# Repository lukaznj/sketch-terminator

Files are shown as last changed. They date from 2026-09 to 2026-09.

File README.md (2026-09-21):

# Sketch Terminator

A 3-DOF robot arm that draws lines between objects it can see.

Point a webcam at a sheet of paper with some objects on it, tell the robot
*"draw a line from the car to the traffic light, but avoid the cat"* in plain
English, and it finds them, plans a path that goes around the cat, and draws it
with a marker.

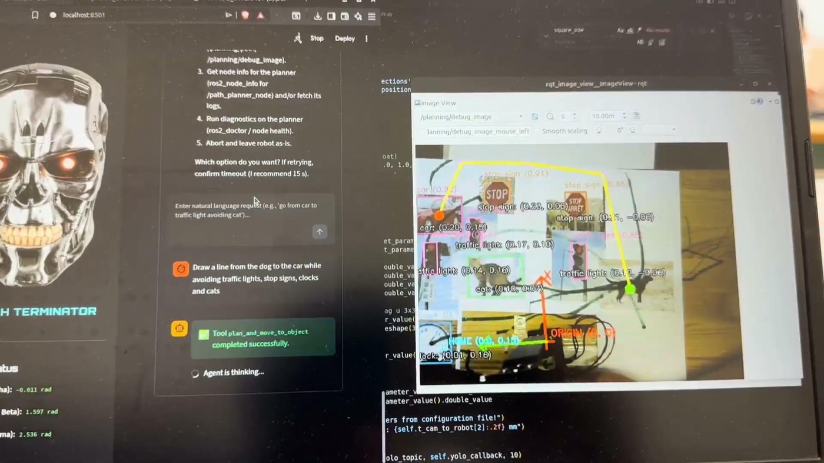
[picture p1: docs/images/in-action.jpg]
The robot in action


---

## What it does

1. **Sees.** A YOLO model detects objects in the camera image, and a
   calibrated projection turns each detection's pixels into real coordinates
   in the robot's own frame.
2. **Plans.** A visibility graph plus A\* finds the shortest path between two
   objects that stays clear of the ones you asked it to avoid.
3. **Draws.** The path is resampled into a constant-speed stream of points,
   inverse kinematics turns each one into joint angles, and the arm draws it,
   lifting the marker for the approach and retreat.
4. **Listens.** An LLM agent ([ROSA](https://github.com/nasa-jpl/rosa)) sits on
   top with tools for each of the above, so the whole thing can be driven
   conversationally.

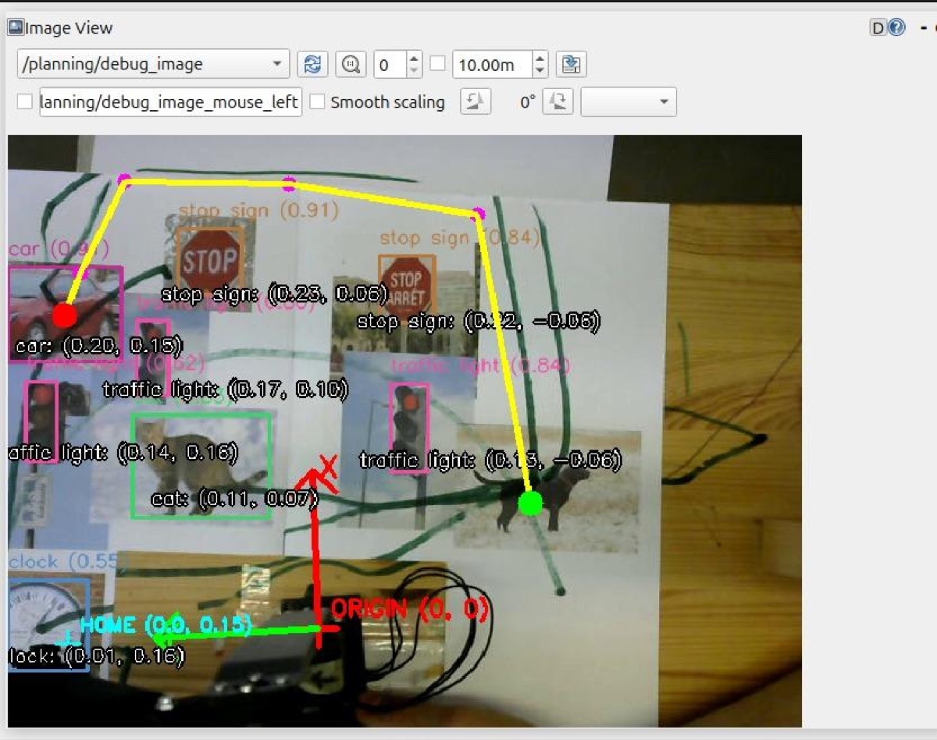
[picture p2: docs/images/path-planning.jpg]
Planned path, drawn back into the camera view


*The planner's debug view: detections in pink, the planned path in yellow,
the robot's origin and axes in red and green.*

## The robot

| | |
|---|---|
| **Joints** | 3: base rotation, shoulder, elbow |
| **Servos** | Dynamixel XL430-W250, IDs 11/12/13 on one 1 Mbps TTL bus |
| **Reach** | ~45 cm (200 mm + 253 mm links) |
| **Drawing speed** | 10 cm/s |
| **Camera** | Any UVC webcam, fixed overhead, 640 × 480 |
| **End effector** | Spring-loaded marker holder, so no fourth axis is needed |
| **Structure** | 3D-printed links on a plywood base |

Full bill of materials, printable files and assembly notes:
**[`hardware/README.md`](hardware/README.md)**

## Architecture

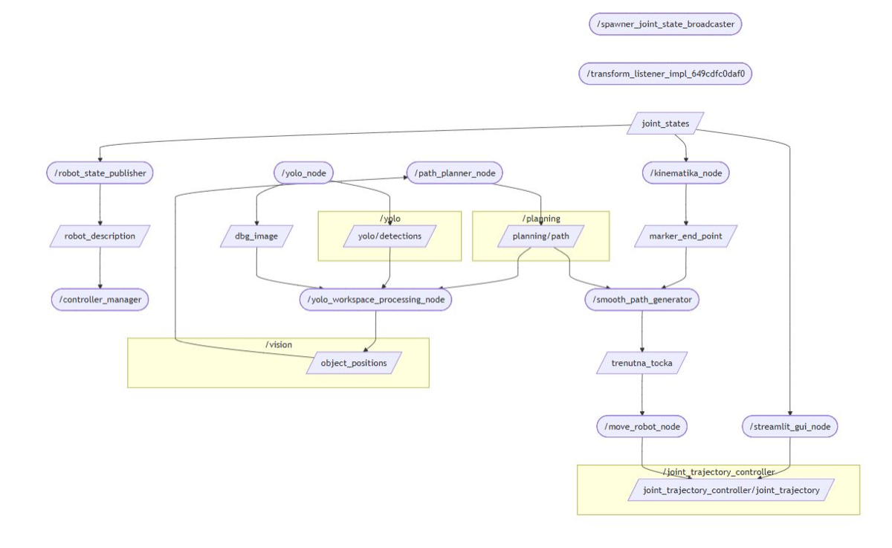
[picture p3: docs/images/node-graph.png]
ROS 2 node graph


The pipeline is a straight line, and each stage is a separate ROS 2 node:

```
camera ──► yolo_node ──► yolo_workspace_processing_node ──► path_planner_node
                                    │                              │
                                    │  /vision/object_positions     │ /planning/path
                                    ▼                              ▼
                                  (JSON)                 generate_smooth_path
                                                                   │ /current_point
                                                                   ▼
kinematics_node ◄── /joint_states ── controllers ◄── move_robot_node
      │                                                    (inverse kinematics)
      └──► /marker_end_point  (start pose for the path generator)
```

| Node | File | Job |
|---|---|---|
| `yolo_node` | [`yolo_node.py`](sketch_terminator/yolo_node.py) | Runs YOLO on the camera stream. |
| `yolo_workspace_processing_node` | [`yolo_workspace_processing_node.py`](sketch_terminator/yolo_workspace_processing_node.py) | Projects detections onto the paper plane; draws the debug overlay. |
| `path_planner_node` | [`path_planner_node.py`](sketch_terminator/path_planner_node.py) | ROS wrapper around the planner. |
| *(library)* | [`visibility_graph.py`](sketch_terminator/visibility_graph.py) | The actual planning: visibility graph + A\*. No ROS, runs standalone. |
| `smooth_path_generator` | [`generate_smooth_path.py`](sketch_terminator/generate_smooth_path.py) | Resamples the path at constant speed; adds pen-up approach and retreat. |
| `move_robot_node` | [`move_robot.py`](sketch_terminator/move_robot.py) | Inverse kinematics → joint trajectories. |
| `kinematics_node` | [`kinematics_node.py`](sketch_terminator/kinematics_node.py) | Forward kinematics from measured joint angles. |
| *(library)* | [`kinematics.py`](sketch_terminator/kinematics.py) | The arm's geometry and joint limits, in one place. |
| `agent_node` | [`agent_node.py`](sketch_terminator/agent_node.py) | The LLM agent, over ROS topics. |
| *(library)* | [`tools.py`](sketch_terminator/tools.py) | The tools the agent can call. |
| *(app)* | [`gui/dashboard.py`](gui/dashboard.py) | Streamlit control panel. |

Both pure-logic modules check themselves, with no test framework needed:

```bash
python3 sketch_terminator/kinematics.py        # IK/DK round-trip
python3 sketch_terminator/visibility_graph.py  # planner geometry
```

## The interface

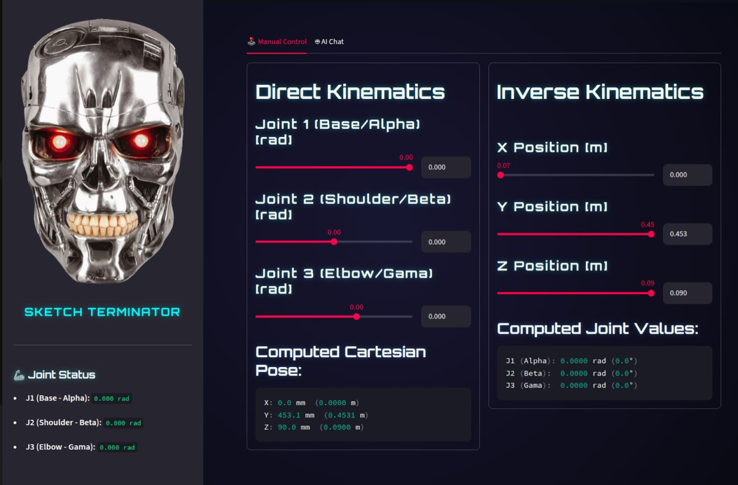
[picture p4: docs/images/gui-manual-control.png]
Manual control tab


The Streamlit dashboard has two tabs. **Manual Control** puts joint sliders
next to Cartesian sliders. Move either and the other follows, and the arm goes
with them. Poses that would drive the marker through the paper are refused.

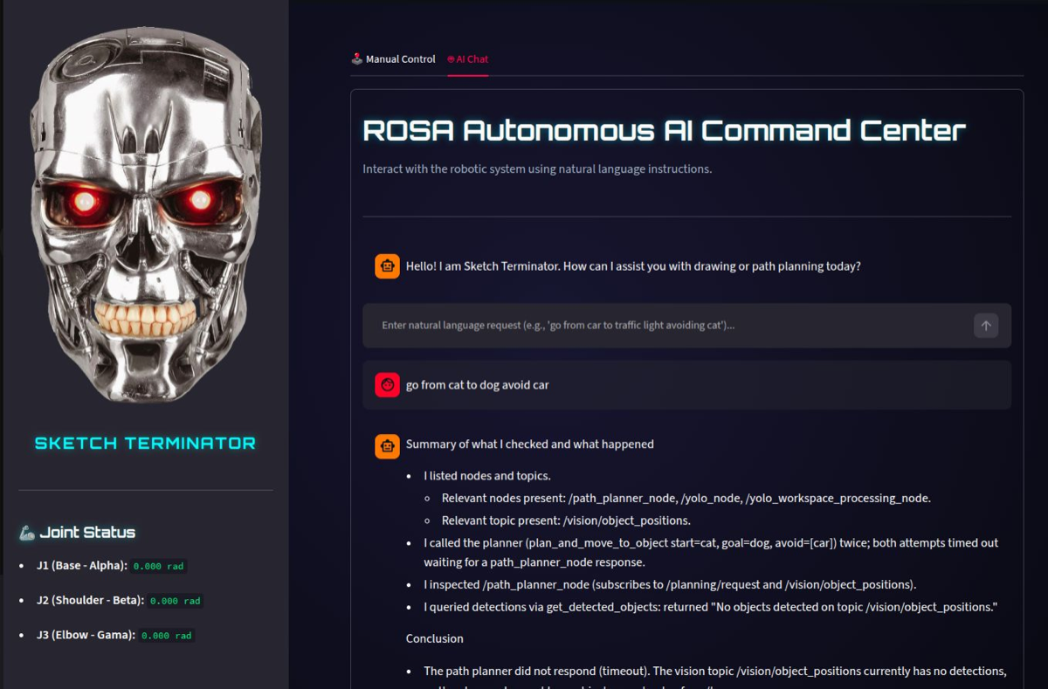
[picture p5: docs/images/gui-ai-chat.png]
AI chat tab


**AI Chat** talks to the ROSA agent, streaming its reasoning and showing which
tool it is running.

---

## Setup

### Prerequisites

- **Ubuntu 24.04** with **ROS 2 Jazzy** ([install guide](https://docs.ros.org/en/jazzy/Installation.html))
- An NVIDIA GPU is recommended for YOLO; it falls back to CPU automatically, just slowly.

### 1. ROS dependencies

```bash
sudo apt update && sudo apt install -y \
  ros-jazzy-ros2-control ros-jazzy-ros2-controllers \
  ros-jazzy-usb-cam ros-jazzy-camera-calibration \
  ros-jazzy-cv-bridge ros-jazzy-xacro ros-jazzy-rviz2 \
  python3-colcon-common-extensions
```

The Dynamixel hardware interface may or may not have a binary release for your
distro. Try apt first, and clone it into your workspace if that comes up empty:

```bash
sudo apt install -y ros-jazzy-dynamixel-hardware \
  || git clone https://github.com/dynamixel-community/dynamixel_hardware.git \
       ~/sketch_ws/src/dynamixel_hardware
```

### 2. Workspace and source

```bash
mkdir -p ~/sketch_ws/src && cd ~/sketch_ws/src
git clone https://github.com/lukaznj/sketch-terminator.git sketch_terminator
```

`yolo_msgs` is not in the ROS index, so clone it alongside:

```bash
git clone https://github.com/mgonzs13/yolo_ros.git
```

### 3. Python dependencies

```bash
pip install ultralytics streamlit python-dotenv rich \
            jpl-rosa langchain-openai
```

### 4. Build

```bash
cd ~/sketch_ws
colcon build --symlink-install
source install/setup.bash
```

Add the source line to your `~/.bashrc` so every new terminal has it.

### 5. API key

The LLM agent needs an OpenAI key. Everything else runs without one.

```bash
cd ~/sketch_ws/src/sketch_terminator
cp config/.env.example config/.env
# edit config/.env and paste your key
```

`config/.env` is gitignored. Do not commit it.

### 6. Hardware

- Set the servo IDs to **11**, **12**, **13** at **1 Mbps** with Dynamixel
  Wizard, before assembling the arm. See
  [`hardware/README.md`](hardware/README.md).
- Give yourself access to the serial port:
  ```bash
  sudo usermod -aG dialout $USER   # log out and back in
  ```
- Check which device the adapter and the camera came up as, and update
  [`urdf/sketch_terminator.ros2_control.xacro`](urdf/sketch_terminator.ros2_control.xacro)
  (`usb_port`) and [`config/camera_params.yaml`](config/camera_params.yaml)
  (`video_device`) if they are not `/dev/ttyUSB0` and `/dev/video0`:
  ```bash
  ls /dev/serial/by-id/
  v4l2-ctl --list-devices
  ```

## Calibration

**Do this before expecting the arm to draw in the right place.** Without it,
the vision pipeline has no idea where the camera is, and every position it
reports is wrong. Redo it whenever the camera moves.

Print a **9 × 7 inner corner** checkerboard, measure one square, and put the
real numbers in [`config/calib_config.yaml`](config/calib_config.yaml).

**Step 1, intrinsics** (lens geometry and distortion):

```bash
ros2 launch sketch_terminator camera_calib.launch.py
```

Move the board around the frame until all four sample bars fill up, click
**CALIBRATE**, then **SAVE**. Copy the resulting values into
[`config/camera_calibration_params.yaml`](config/camera_calibration_params.yaml).

**Step 2, extrinsics** (where the camera is, relative to the robot):

```bash
ros2 launch sketch_terminator camera_world.launch.py
```

Tape the board flat in view, measure its offset from the base of the arm, and
put those offsets in `calib_config.yaml`. The node prints a 4 × 4 transform;
copy its rotation into `R_cam_to_robot` and its translation (**in
millimetres**, so metres × 1000) into `t_cam_to_robot`, both in
[`config/vision_config.yaml`](config/vision_config.yaml).

**Step 3, check it.** Put a red marker at a spot you have measured and confirm
the position the node prints matches. If everything is off by a consistent
amount, trim `offset_x_m` / `offset_y_m` in `vision_config.yaml` rather than
redoing the transform.

## Running it

Everything at once, meaning hardware, vision, planning, RViz and the dashboard:

```bash
ros2 launch sketch_terminator master_robot.launch.py
```

Then open **http://localhost:8501**.

Vision and planning only, with no motors powered:

```bash
ros2 launch sketch_terminator vision.launch.py
```

To watch what the vision pipeline sees:

```bash
ros2 run rqt_image_view rqt_image_view /planning/debug_image
```

You can also drive it from the command line, without the GUI:

```bash
ros2 topic pub --once /planning/request std_msgs/String \
  '{data: "{\"start_class\": \"car\", \"goal_class\": \"traffic light\", \"avoid_classes\": [\"cat\"]}"}'
```

The class names are whatever your YOLO weights were trained on. The defaults
are the 80 COCO classes, which is why the demo uses cars, cats and traffic
lights.

## Troubleshooting

| Symptom | Cause |
|---|---|
| Arm does not move, no errors | The controllers spawned before the hardware was found. Check `ros2 control list_controllers`, and that the servos are powered (the U2D2 alone does not power them). |
| `Failed to open port` | Wrong `usb_port`, or you are not in the `dialout` group. |
| Arm moves to the wrong place | Calibration. Redo it, then trim `offset_x_m` / `offset_y_m`. |
| Nothing detected | Check `/dbg_image` first. Usually lighting, or objects the model was never trained on. |
| Agent times out | `agent_node` is not running, or `OPENAI_API_KEY` is missing from `config/.env`. |
| Arm jitters near its own base | Expected, because the base yaw is ill-conditioned there. `MIN_RADIUS` in `kinematics.py` keeps targets out of that region. |

## Repository layout

```
config/            camera, calibration and vision parameters
controllers/       ros2_control configuration
docs/              presentation and images
gui/               Streamlit dashboard
hardware/          printable parts, reference CAD, build guide
launch/            launch files
meshes/            STL meshes for the robot model
scripts/           camera-to-robot calibration tool
sketch_terminator/ the ROS 2 nodes
urdf/              robot model and hardware interface
```

## Documentation

The [project presentation](docs/presentation.pdf) covers the kinematics
derivation, the path planning approach and photos of the build.

## Team

Built by a five-person team for the Robotics Practicum course, 2025/2026.

## License

[Apache 2.0](LICENSE)

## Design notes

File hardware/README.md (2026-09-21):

# Hardware

Everything you need to build the arm: what to buy, what to print, and how it
goes together.

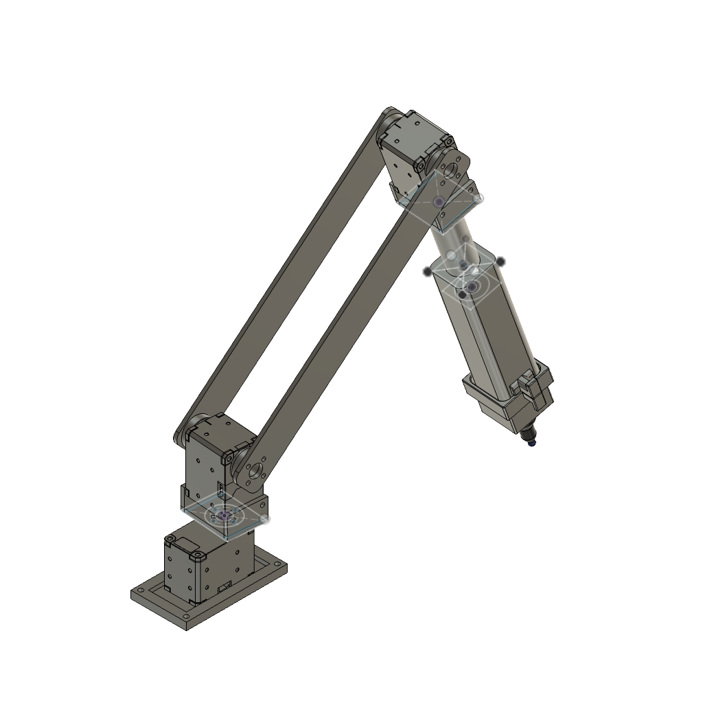
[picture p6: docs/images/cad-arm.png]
The assembled arm


## Bill of materials

| Part | Qty | Notes |
|---|---|---|
| Dynamixel **XL430-W250-T** servo | 3 | The whole arm. Any X-series servo with the same 28.5 × 46.5 × 34 mm body drops in without reprinting anything. |
| ROBOTIS **U2D2** USB adapter | 1 | Talks to the servo bus from the PC. |
| **U2D2 Power Hub** (or equivalent) | 1 | Injects 12 V into the daisy chain. |
| 12 V ≥ 2 A power supply | 1 | The XL430 is rated for 11.1 V; 12 V is the usual supply. |
| Dynamixel 3-pin TTL cables | 3–4 | One per servo plus one to the adapter. |
| **FP04-F2 / HN11-N1** style brackets | 2 | The frames that bolt onto the servo horns. Usually included with the servos. |
| M2.5 × 8 mm screws | ~20 | Servo mounting. |
| M3 × 12 mm screws + nuts | ~8 | Printed parts. |
| USB webcam (UVC, 640 × 480 or better) | 1 | Any webcam Linux exposes as `/dev/videoN`. |
| Whiteboard marker, ~18 mm barrel | 1 | Drops into the pen holder. |
| Compression spring, 9.5 × 17.5 mm | 1 | Keeps constant pressure on the paper. |
| Plywood / MDF base board | 1 | ~50 × 50 cm, plus an overhead frame for the camera. |

> The arm was built with **XL430-W250** servos. They are the cheap end of the
> X-series and are adequate here because the arm only carries a marker. They
> are plastic-geared, though, so do not add mass to the end effector without
> moving up to an XM430.

## Parts to 3D print

All files are in [`print/`](print/) as `.3mf`, exported from Fusion 360 and
ready to slice.

| File | Qty | What it is |
|---|---|---|
| [`base.3mf`](print/base.3mf) | 1 | Foot that bolts to the board and holds the base servo. |
| [`link-90-bracket.3mf`](print/link-90-bracket.3mf) | 1 | Right-angle bracket between the base servo and the shoulder servo. |
| [`long-link.3mf`](print/long-link.3mf) | 2 | The two parallel arm links. **Print two.** |
| [`pen-holder.3mf`](print/pen-holder.3mf) | 1 | Sleeve the marker slides into. |
| [`pen-holder-mount.3mf`](print/pen-holder-mount.3mf) | 1 | Carries the sleeve and bolts to the elbow servo. |
| [`pen-holder-stopper.3mf`](print/pen-holder-stopper.3mf) | 1 | Caps the sleeve and traps the spring. |

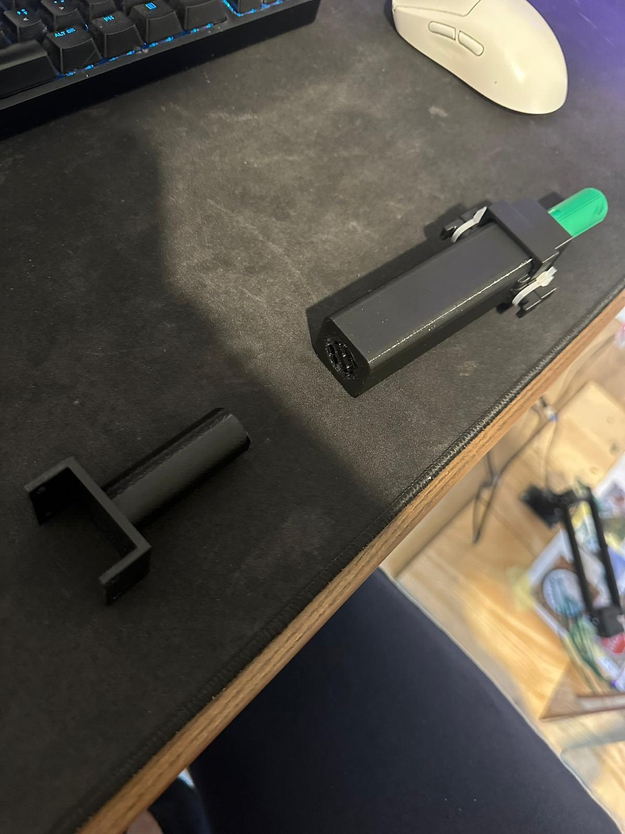
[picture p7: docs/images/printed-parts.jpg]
Printed parts


### Print settings

Nothing here is exotic. These settings were used for the parts in the photo:

| Setting | Value |
|---|---|
| Material | PLA |
| Layer height | 0.2 mm |
| Walls | 3 |
| Infill | 25 % gyroid |
| Supports | None needed; every part is oriented to print support-free |

The long links take the most load; if yours flex noticeably under the arm's own
weight, raise the wall count to 4 rather than the infill.

## Reference models

[`reference/`](reference/) holds geometry that is **not** printed. The servo
body, the marker and the spring are there so the assemblies show the real fit,
and the two assembly files are how the whole thing goes together.

| File | What it is |
|---|---|
| `full-arm-assembly.3mf` | The complete arm. Open this first to see how everything mates. |
| `pen-holder-assembly.3mf` | The end effector exploded out: sleeve, mount, stopper, spring, marker. |
| `dynamixel-xl430-w250.3mf` | Servo body, for fit checks. |
| `marker-pen.3mf` | The marker, for fit checks. |
| `compression-spring.3mf` | The spring, for fit checks. |
| `legacy-*.step` | Earlier design iterations, kept for reference. |

## The end effector

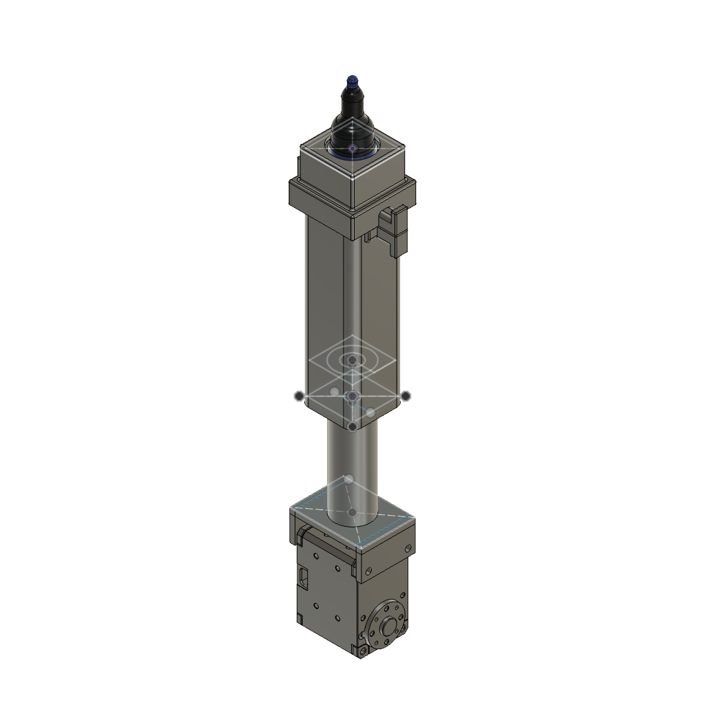
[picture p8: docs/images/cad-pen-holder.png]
Pen holder assembly


The marker is not driven up and down. The arm has only three joints, and all
three are used for positioning. Instead the marker floats inside its sleeve on
the compression spring:

- The arm drives the sleeve to **Z = 0**, slightly *into* the paper.
- The spring compresses and holds the tip down at roughly constant force.
- The stopper caps the top of the sleeve so the marker cannot be pushed out.

That means line weight stays even across the sheet without the paper having to
be perfectly flat or the Z calibration having to be perfect. It is also why
`Z_MAX` in the software is a hard limit: lifting past the shoulder pivot is
what clears the marker from the paper.

## Assembly notes

1. **Set the servo IDs first.** Connect each servo on its own with Dynamixel
   Wizard and set the IDs to **11** (shoulder), **12** (elbow) and **13**
   (base), all at **1 Mbps**. These are what
   [`urdf/sketch_terminator.ros2_control.xacro`](../urdf/sketch_terminator.ros2_control.xacro)
   expects. Doing this after assembly means taking the arm apart again.
2. **Centre every servo** (position 2048 / 180°) before bolting the horns on,
   so the mechanical zero matches the model's zero.
3. Bolt the base to the board. The arm's coordinate origin is the centre of the
   base servo's rotation axis, so measure everything else from there.
4. Daisy-chain the three servos and connect the chain to the U2D2, with the
   power hub injecting 12 V.
5. Mount the camera on an overhead frame looking straight down at the paper,
   roughly **65–70 cm** above it, with the whole drawing area in view and the
   arm's base at the edge of the frame. Anything rigid works; the one in the
   photos is scrap plywood.
6. Tape the calibration checkerboard flat inside the camera's view and measure
   its offset from the base. Those numbers go in
   [`config/calib_config.yaml`](../config/calib_config.yaml).

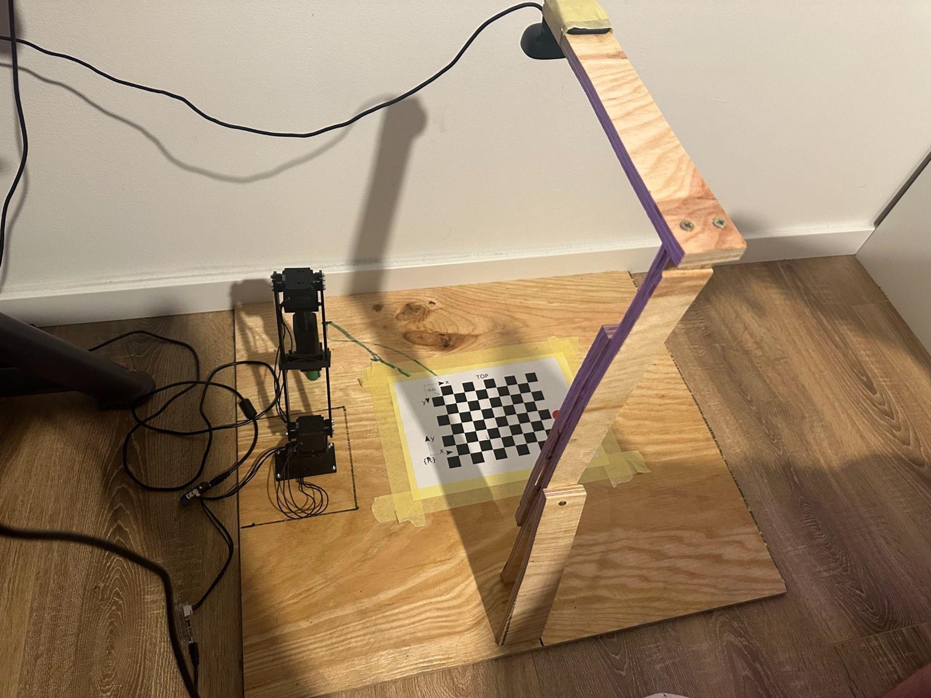
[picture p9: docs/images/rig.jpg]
The rig


Once it is built, follow the calibration steps in the
[main README](../README.md#calibration), because the arm cannot draw anywhere
near the right place until the camera is calibrated.

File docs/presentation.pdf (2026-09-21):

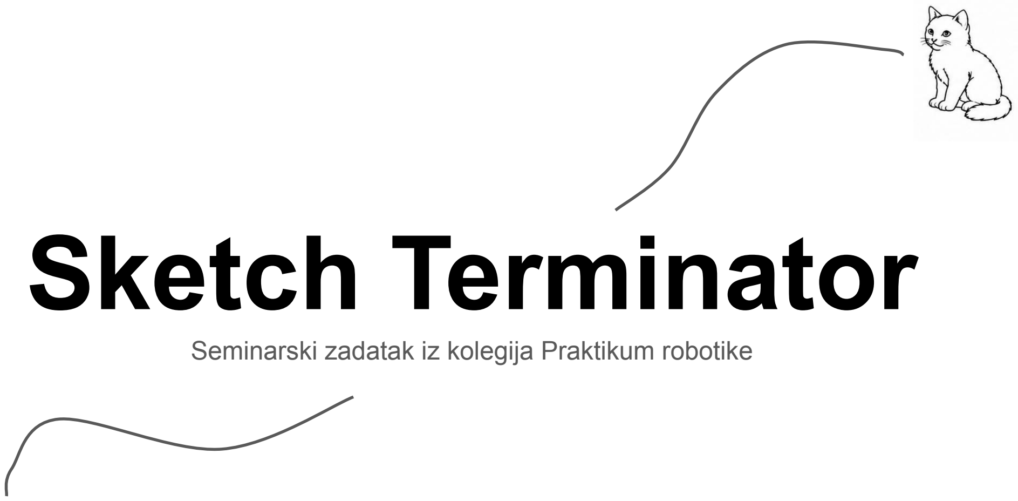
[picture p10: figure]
Sketch Terminator

Grupa SEM3 | Borna Dorontić, Josip Dugandžić, Ivan Marfat, Roko Milić, Luka Ražem | Ak. God. 2025/2026

Seminarski zadatak iz kolegija Praktikum robotike

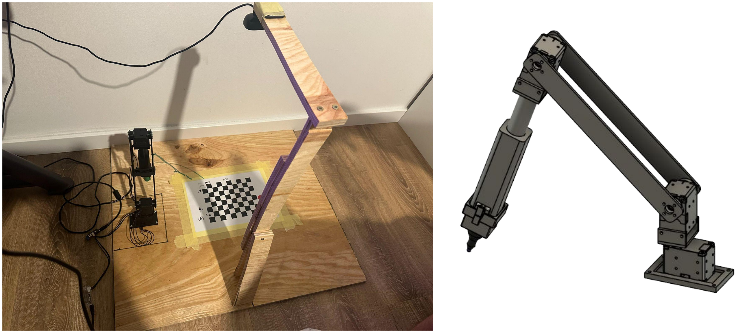
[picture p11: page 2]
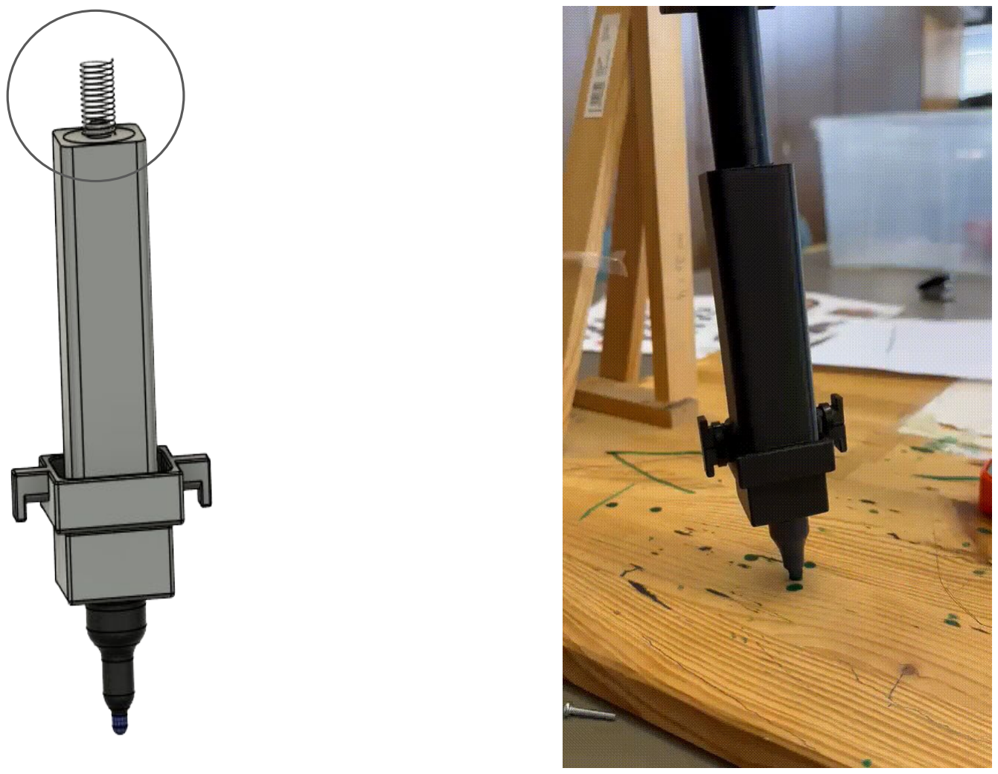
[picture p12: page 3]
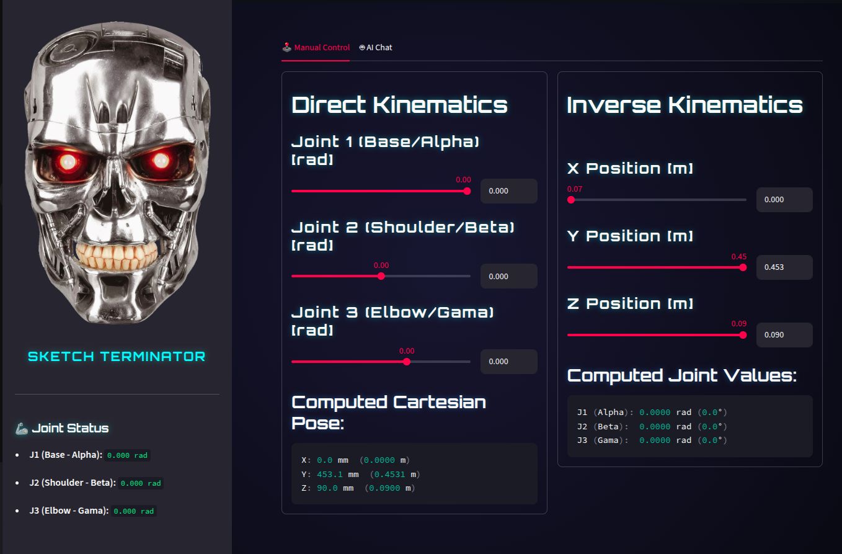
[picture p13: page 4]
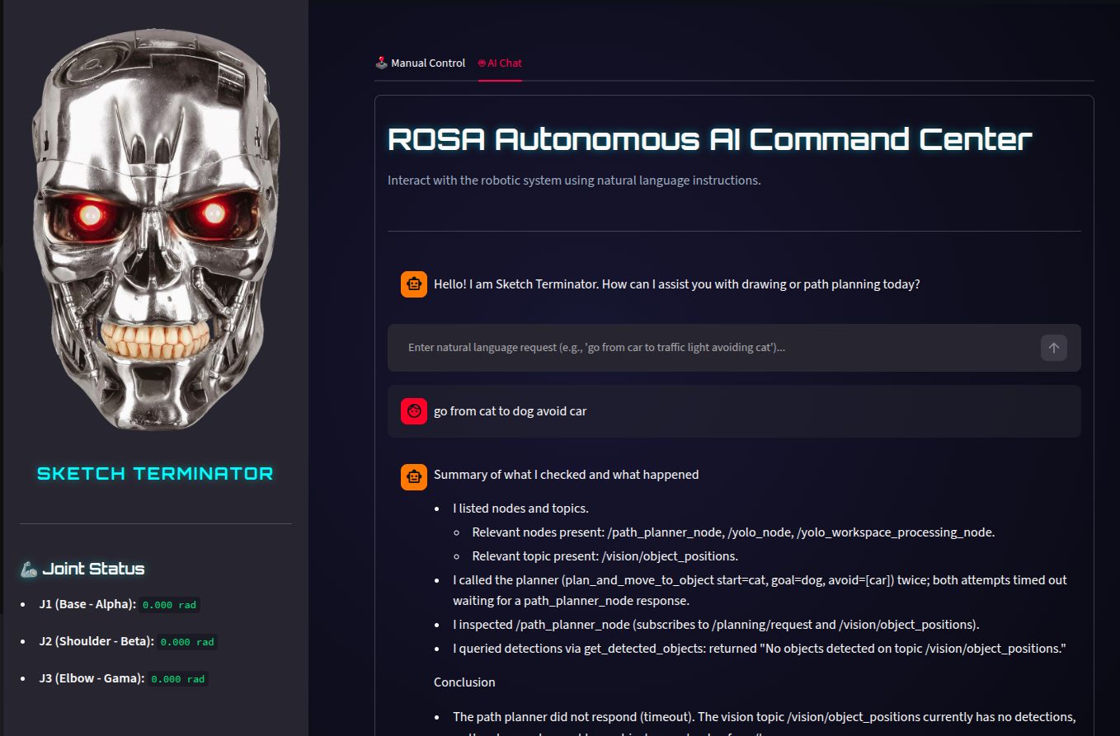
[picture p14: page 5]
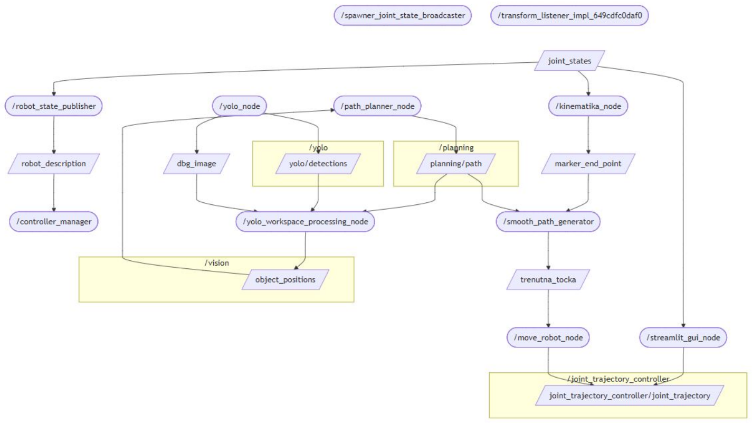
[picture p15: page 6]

## Path planning

- Sustav prima naredbu koje objekte

treba povezati i koje treba izbjeći

- Kamera detektira objekte i njihove

pozicije u radnom prostoru

- Algoritam provjerava prolazi li

direktna linija kroz prepreku

- Ako postoji prepreka, dodaje se

waypoint za zaobilaženje

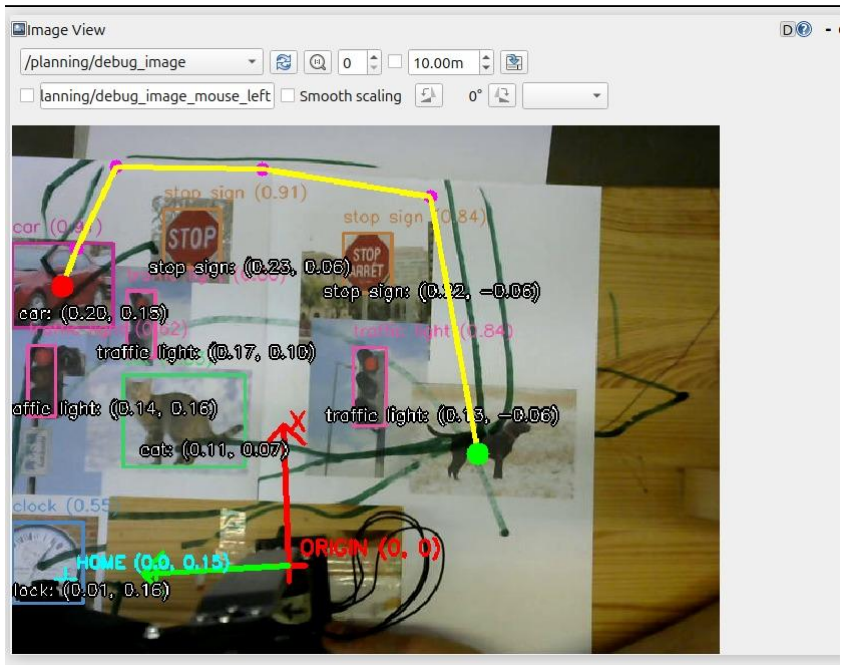
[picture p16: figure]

Primjer isplanirane putanje: žuta linija prikazuje isplaniranu putanju robota

## Inverzna kinematika i interpolacija puta

Node generate_smooth_path uzima točke koje šalje path_planner_node i generira glatku putanju u vremenu od ~100 točaka koje se šalju node-u za inverznu kinematiku

Točke šalje tako da se osigura sigurna brzina robota od oko 10cm/s

Osigurava da robot ne crta dok dolazi do početnog objekta, nakon crtanja vraća robota u poziciju gdje ne blokira pogled kameri

Node za inverznu kinematiku iz zadane točke računa i publisha potrebne zakrete motora

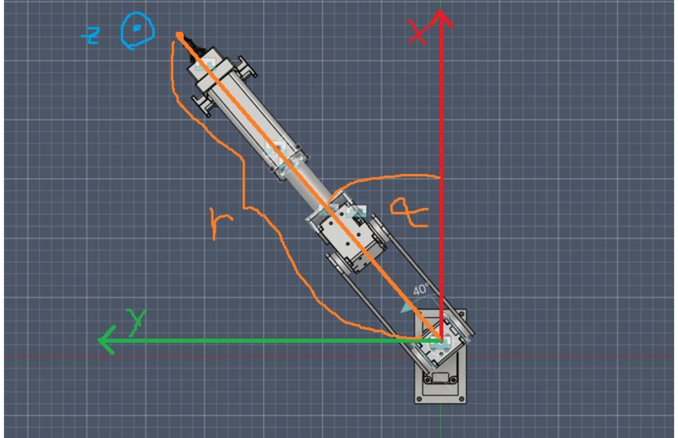
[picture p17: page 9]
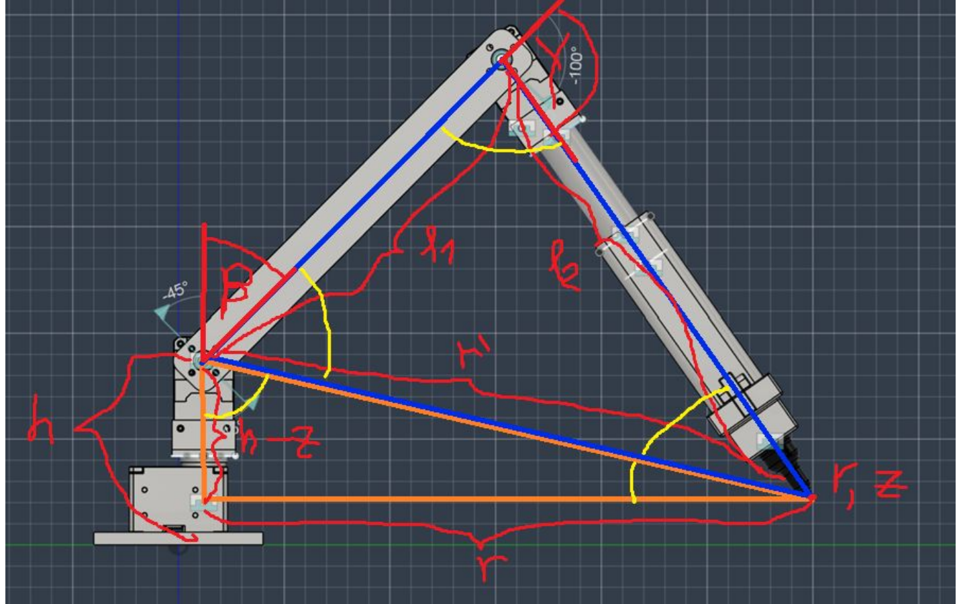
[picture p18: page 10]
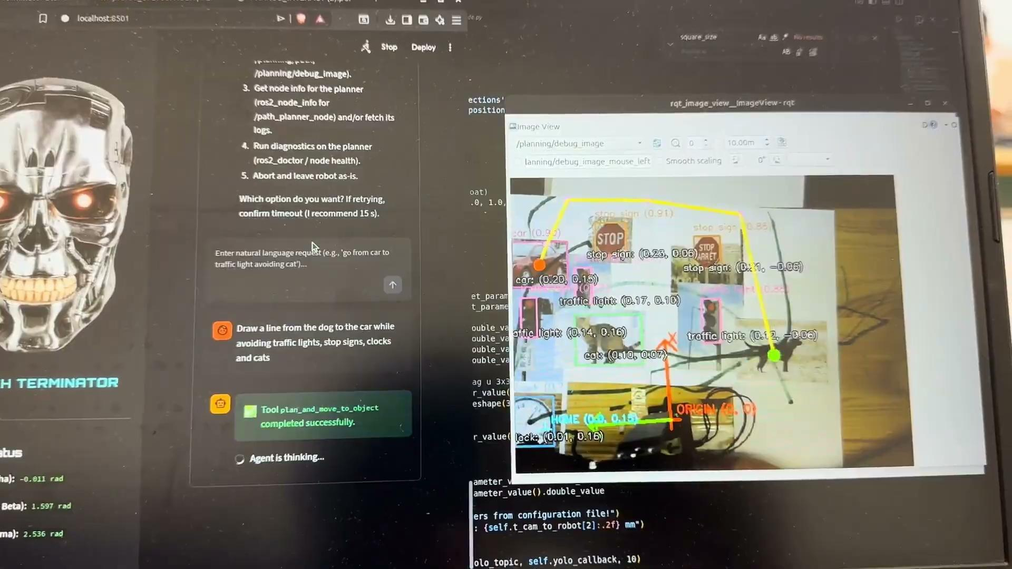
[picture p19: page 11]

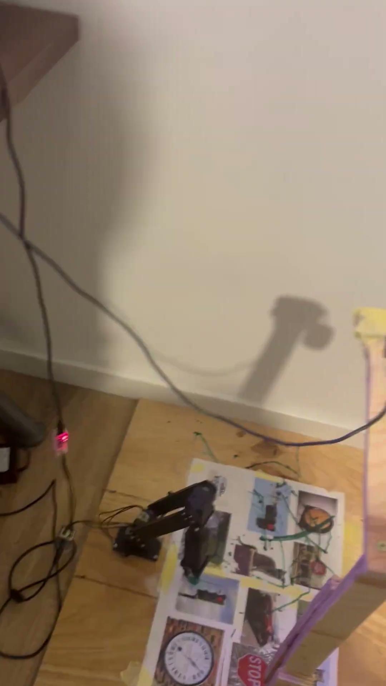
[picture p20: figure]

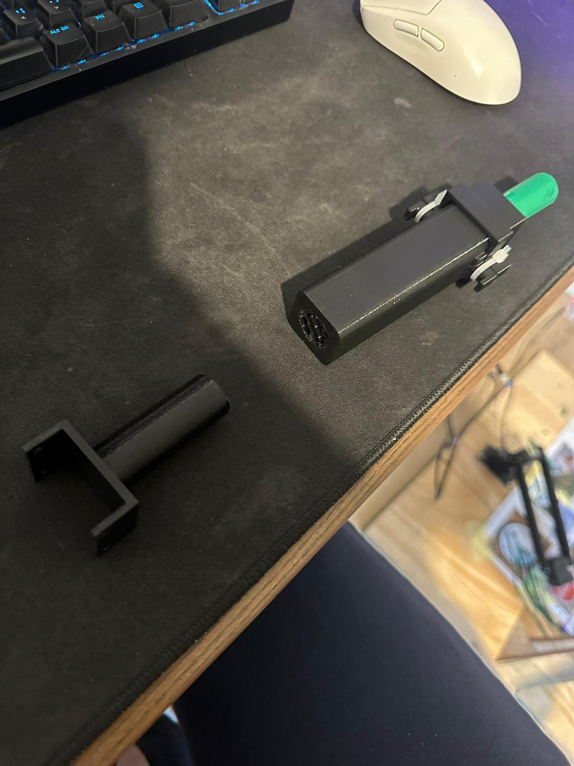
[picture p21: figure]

# “Vi ste jedina grupa koja je više truda uložila u GUI nego u dizajn robota”

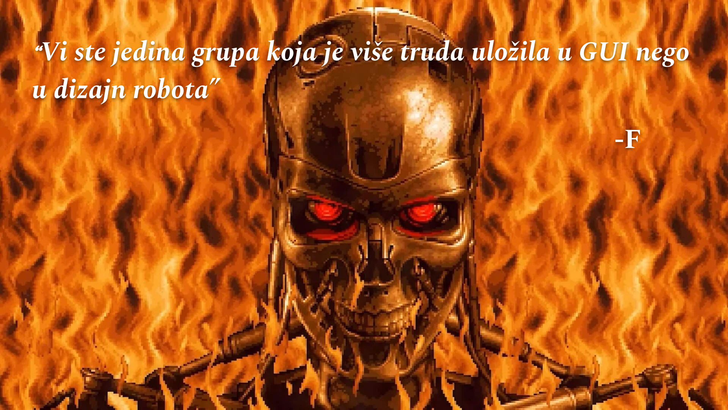
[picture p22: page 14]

-F

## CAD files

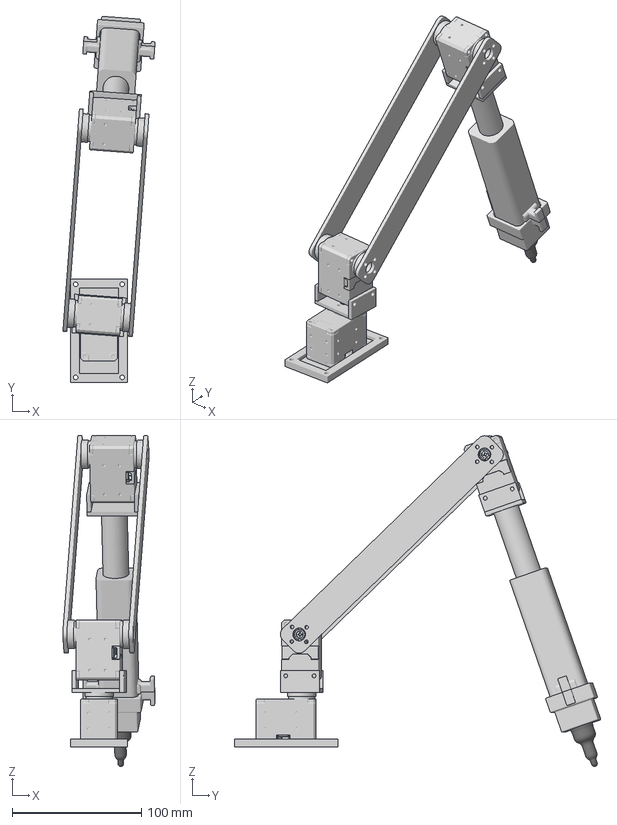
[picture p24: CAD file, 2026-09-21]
hardware/reference/full-arm-assembly.3mf
71.3 x 283.2 x 255.9 mm

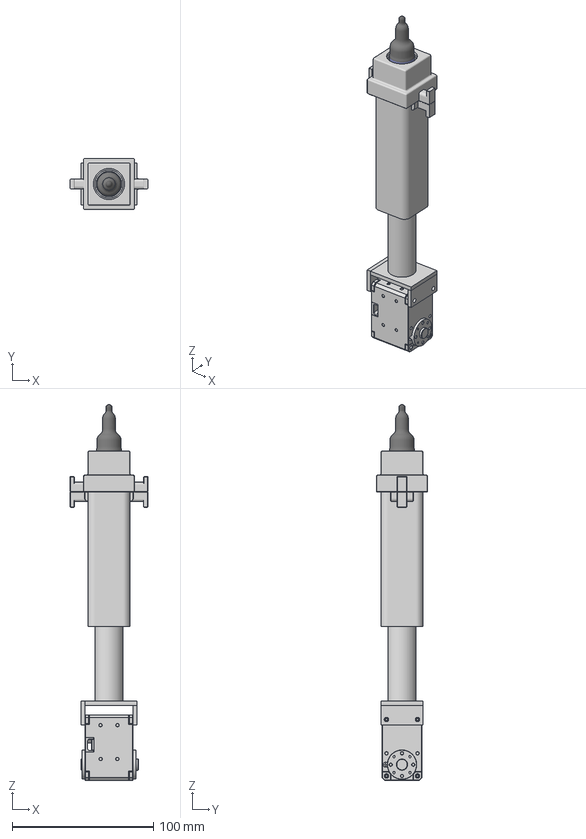
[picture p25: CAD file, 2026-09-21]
hardware/reference/pen-holder-assembly.3mf
55.2 x 36.2 x 266.6 mm

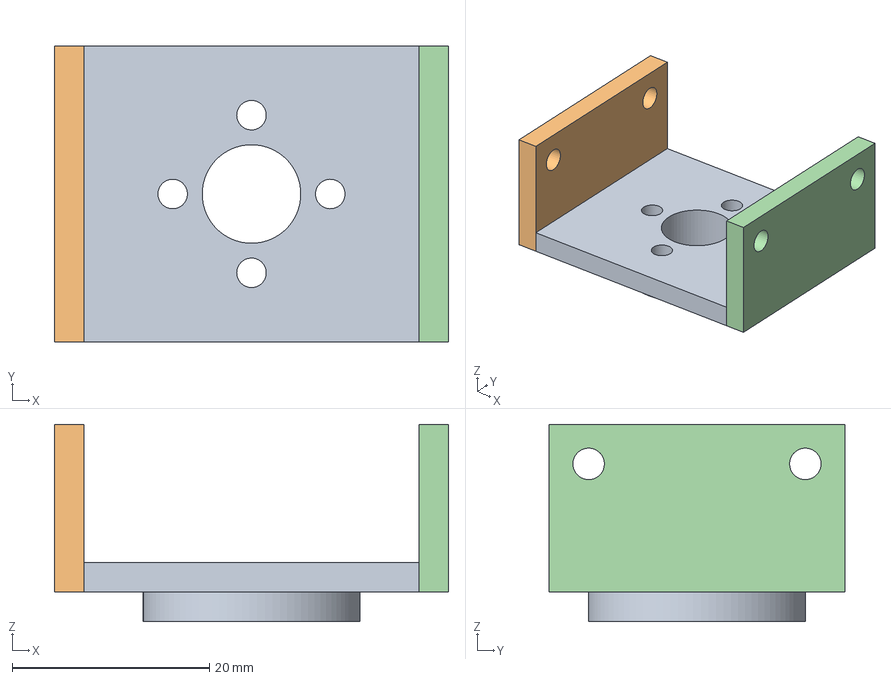
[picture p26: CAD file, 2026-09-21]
hardware/print/link-90-bracket.3mf
40.0 x 30.0 x 20.0 mm

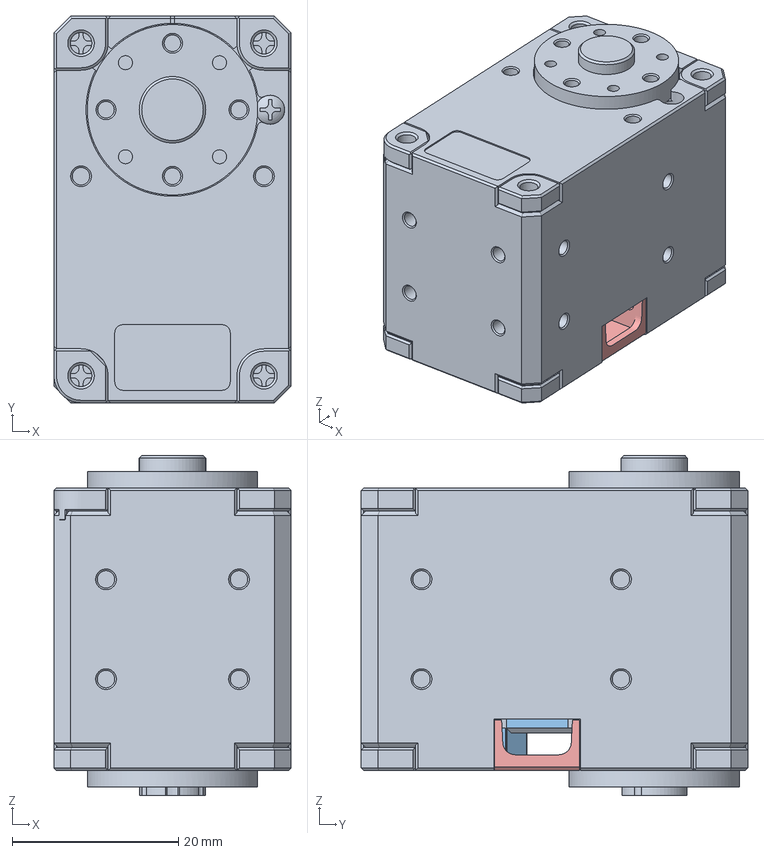
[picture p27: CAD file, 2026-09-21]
hardware/reference/dynamixel-xl430-w250.3mf
28.5 x 46.5 x 40.9 mm

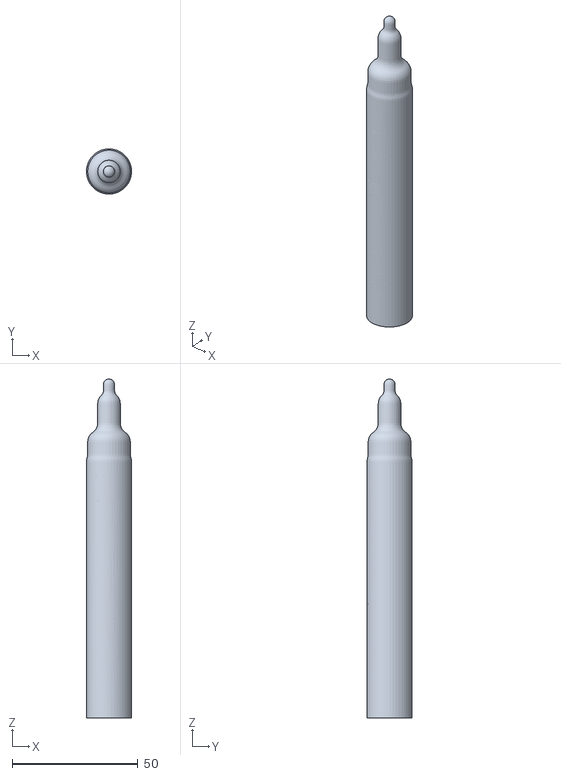
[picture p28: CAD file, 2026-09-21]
meshes/marker.stl
18.0 x 18.0 x 135.0

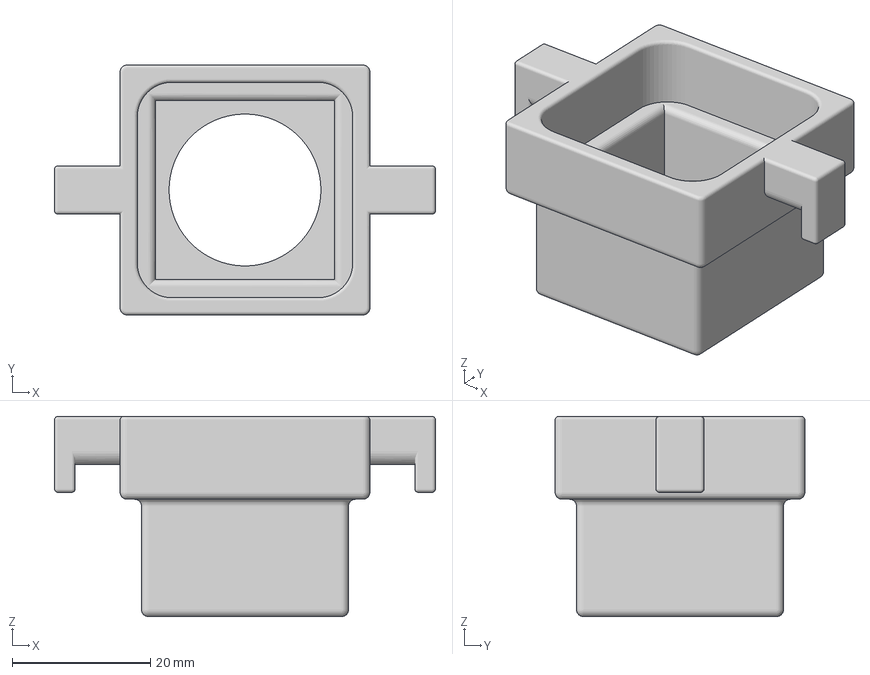
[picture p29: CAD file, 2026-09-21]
hardware/print/pen-holder-stopper.3mf
55.2 x 36.2 x 29.0 mm

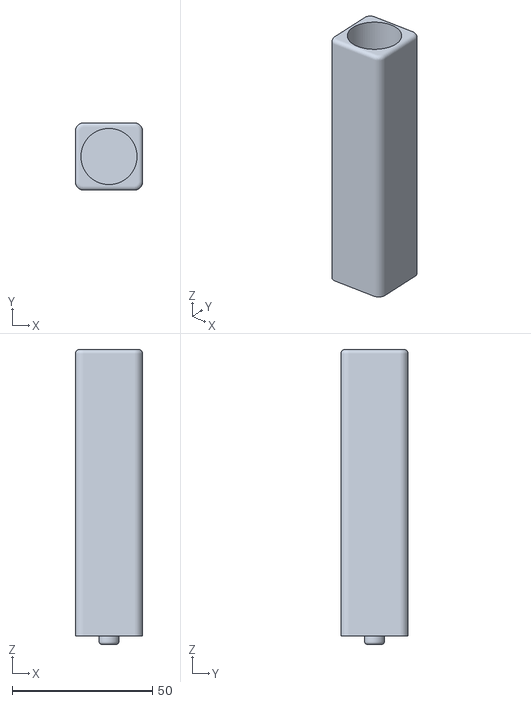
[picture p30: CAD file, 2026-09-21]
meshes/pen_holder.stl
24.0 x 24.0 x 105.0

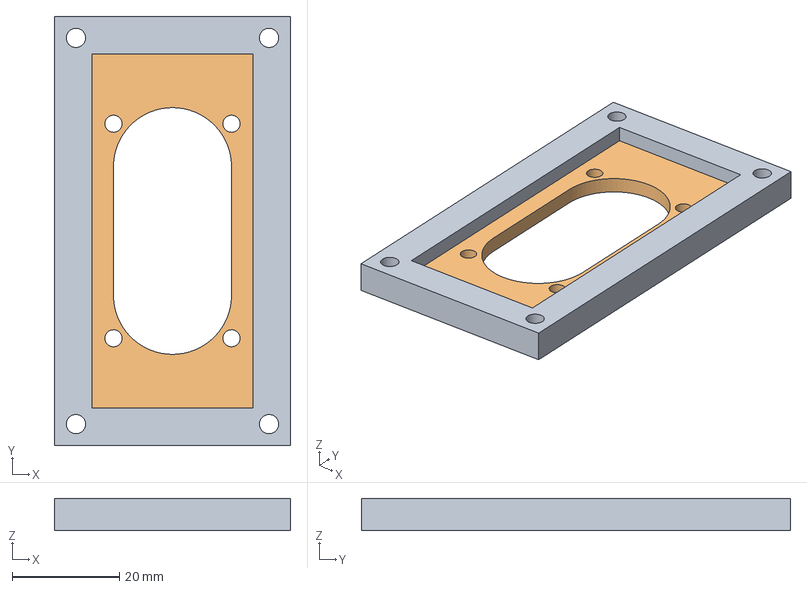
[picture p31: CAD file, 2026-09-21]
hardware/print/base.3mf
44.0 x 80.0 x 6.00 mm

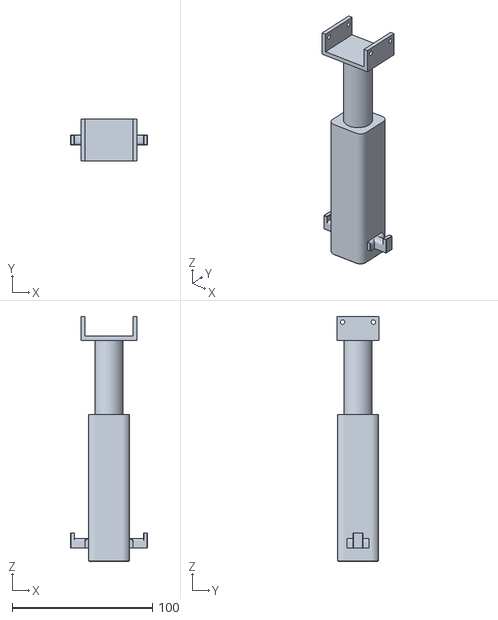
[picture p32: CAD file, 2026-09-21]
meshes/pen_holder_mount.stl
55.2 x 30.0 x 175.0

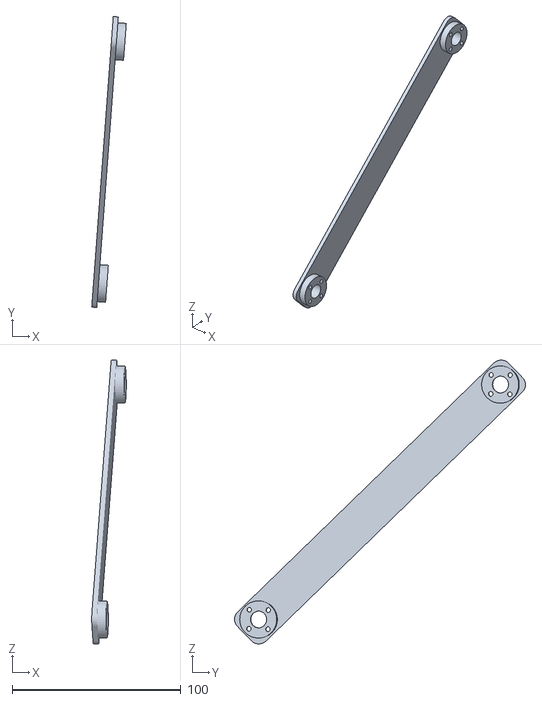
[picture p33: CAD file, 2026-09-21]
meshes/long_link_1.stl
20.5 x 172.4 x 168.1

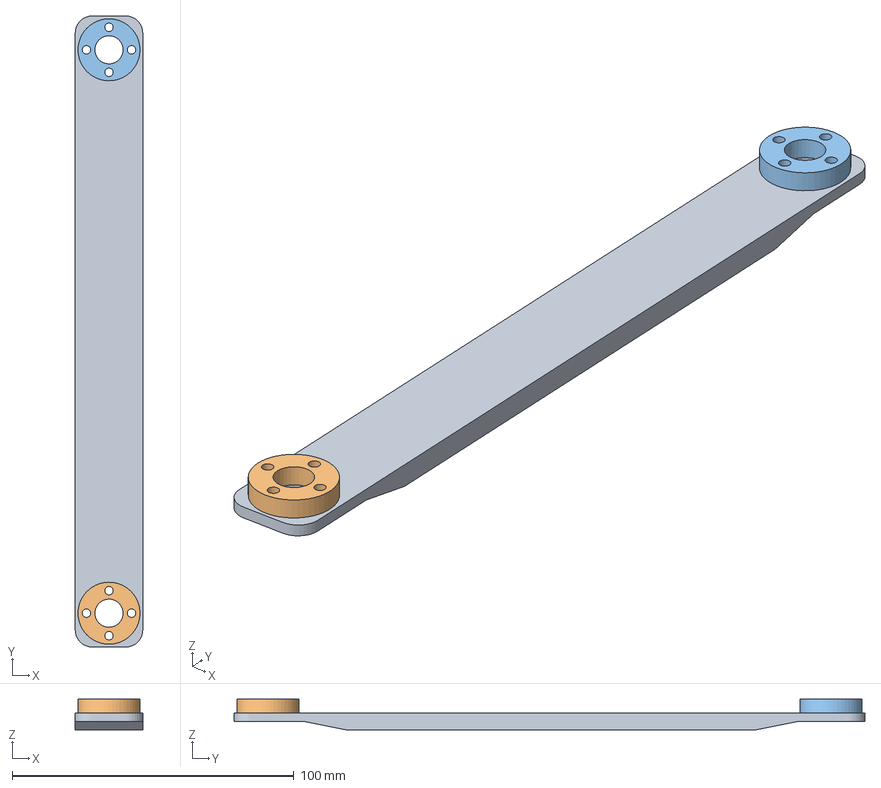
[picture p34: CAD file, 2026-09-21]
hardware/print/long-link.3mf
24.0 x 224.0 x 11.0 mm

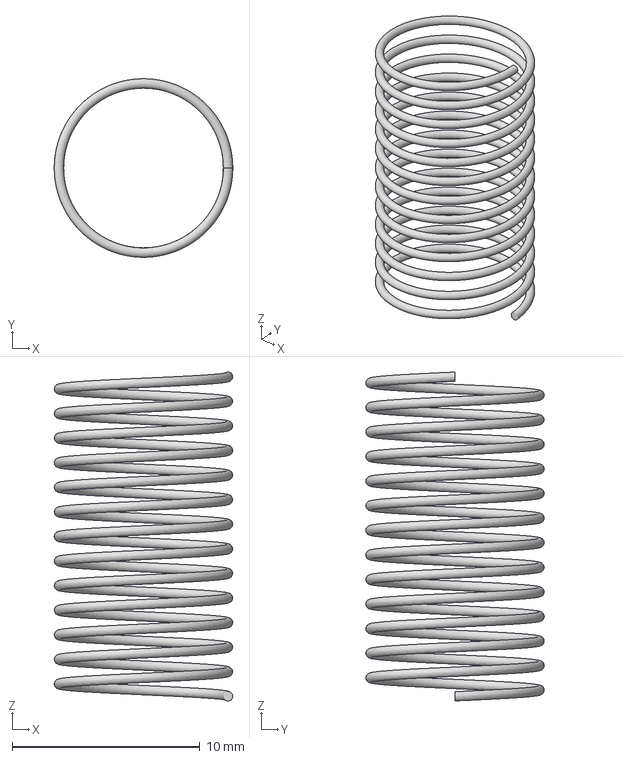
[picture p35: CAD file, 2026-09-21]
hardware/reference/compression-spring.3mf
9.50 x 9.50 x 17.5 mm

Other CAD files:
hardware/print/pen-holder.3mf
meshes/pen_holder_stopper.stl
hardware/print/pen-holder-mount.3mf
meshes/long_link_2.stl
meshes/base_link.stl
hardware/reference/marker-pen.3mf
hardware/reference/legacy-arm-v1.step
hardware/reference/legacy-arm-v2.step
hardware/reference/legacy-base-plate.step
meshes/dynamixel_xl430.stl
meshes/link_90_bracket.stl
meshes/spring.stl

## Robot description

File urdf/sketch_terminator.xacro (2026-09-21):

<?xml version="1.0" ?>
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
<robot name="sketch_terminator" xmlns:xacro="http://www.ros.org/wiki/xacro">

  <xacro:include filename="materials.xacro" />

  <xacro:property name="half_pi" value="${pi/2}"/>
  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
  <xacro:property name="link_mesh_rpy" value="1.185714 1.513363 1.955879"/>

  <link name="world"/>

  <link name="base_link">
    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
    <inertial>
      <origin xyz="-0.0001 0.0 0.00261" rpy="0 0 0"/>
      <mass value="0.09510119488113095"/>
      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
    </inertial>
  </link>

  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
  <link name="DC11_A01_DUMMY_1">
    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
    <inertial>
      <origin xyz="0.00884 0.0 0.0" rpy="0 0 0"/>
      <mass value="0.3426594534663265"/>
      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
    </inertial>
  </link>

  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
  <link name="bracket_pivot"/>

  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
  <link name="Link_90_1">
    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
    <inertial>
      <origin xyz="0.00545 -0.00040 0.00831" rpy="0 0 0"/>
      <mass value="0.07870797232814769"/>
      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
    </inertial>
  </link>

  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
  <link name="DC11_A01_DUMMY_2">
    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
    <inertial>
      <origin xyz="0.0 0.00884 0.0" rpy="0 0 0"/>
      <mass value="0.3426594534663265"/>
      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
    </inertial>
  </link>

  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
  <link name="shoulder_pivot"/>

  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
  <link name="Long_Link_1">
    <inertial>
      <origin xyz="-0.00056 0.07207 0.06957" rpy="0 0 0"/>
      <mass value="0.14230160280394566"/>
      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
    </inertial>
    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
  </link>

  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
  <link name="Long_Link_2">
    <inertial>
      <origin xyz="0.01120 0.07120 0.06957" rpy="0 0 0"/>
      <mass value="0.14230160280394566"/>
      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
    </inertial>
    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
  </link>

  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
  <joint name="world_joint" type="fixed">
    <parent link="world"/>
    <child link="base_link"/>
    <origin xyz="0 0 0" rpy="0 0 0"/>
  </joint>

  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
  <joint name="Revolute_1" type="fixed">
    <parent link="base_link"/>
    <child link="DC11_A01_DUMMY_1"/>
    <origin xyz="0 0.012 0.02" rpy="0 0 0"/>
  </joint>

  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
  <joint name="joint3" type="revolute">
    <parent link="DC11_A01_DUMMY_1"/>
    <child link="bracket_pivot"/>
    <origin xyz="0 0 0.029" rpy="0 0 0"/>
    <axis xyz="0 0 1"/>
    <limit lower="-${half_pi}" upper="${half_pi}" effort="100" velocity="1.0"/>
  </joint>

  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
  <joint name="joint_bracket" type="fixed">
    <parent link="bracket_pivot"/>
    <child link="Link_90_1"/>
    <origin xyz="0 -0.012 -0.049" rpy="0 0 0"/>
  </joint>

  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
  <joint name="Revolute_2b" type="fixed">
    <parent link="Link_90_1"/>
    <child link="DC11_A01_DUMMY_2"/>
    <origin xyz="0 0.0115 0.086" rpy="${half_pi} 0 ${half_pi}"/>
  </joint>

  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
  <joint name="joint1" type="revolute">
    <parent link="DC11_A01_DUMMY_2"/>
    <child link="shoulder_pivot"/>
    <origin xyz="-0.001 0 0.024" rpy="0 0 -${half_pi}"/>
    <axis xyz="0 0 1"/>
    <limit lower="-${half_pi}" upper="${half_pi}" effort="100" velocity="1.0"/>
  </joint>

  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
  <joint name="joint_longlinks" type="fixed">
    <parent link="shoulder_pivot"/>
    <child link="Long_Link_1"/>
    <origin xyz="-0.053 -0.068 -0.026" rpy="0 0 0"/>
  </joint>

  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
  <joint name="Revolute_6" type="fixed">
    <parent link="Long_Link_1"/>
    <child link="Long_Link_2"/>
    <origin xyz="0 0 0" rpy="0 0 0"/>
  </joint>

  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
  <link name="wrist_pivot"/>

  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
  <link name="DC11_A01_DUMMY_3">
    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
    <inertial>
      <origin xyz="0.0 0.00884 0.0" rpy="0 0 0"/>
      <mass value="0.3426594534663265"/>
      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
    </inertial>
  </link>

  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
  <link name="penholder">
    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
    <inertial>
      <origin xyz="0 0 -0.07" rpy="0 0 0"/>
      <mass value="0.05"/>
      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
    </inertial>
  </link>

  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
  <joint name="joint2" type="revolute">
    <parent link="Long_Link_2"/>
    <child link="wrist_pivot"/>
    <origin xyz="0.0525 0.270 0.004" rpy="-${half_pi} ${half_pi} 0"/>
    <axis xyz="1 0 0"/>
    <limit lower="-${half_pi}" upper="${half_pi}" effort="100" velocity="1.0"/>
  </joint>

  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
  <joint name="joint_motor3" type="fixed">
    <parent link="wrist_pivot"/>
    <child link="DC11_A01_DUMMY_3"/>
    <origin xyz="0 0 -0.0775" rpy="0 0 0"/>
  </joint>

  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
  <joint name="joint_penholder" type="fixed">
    <parent link="DC11_A01_DUMMY_3"/>
    <child link="penholder"/>
    <origin xyz="0 0 0.2" rpy="0 0 0"/>
  </joint>

  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
  <link name="spring">
    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
    <inertial>
      <origin xyz="0 0 0" rpy="0 0 0"/>
      <mass value="0.01"/>
      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
    </inertial>
  </link>

  <joint name="joint_spring" type="fixed">
    <parent link="penholder"/>
    <child link="spring"/>
    <origin xyz="0 0 0" rpy="0 0 0"/>
  </joint>

</robot>

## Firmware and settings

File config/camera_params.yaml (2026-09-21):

# usb_cam driver settings.
#
# video_device is the one thing you will almost certainly have to change:
# run `v4l2-ctl --list-devices` to find the right node for your camera.

/**:
    ros__parameters:
      video_device: "/dev/video0"
      framerate: 30.0
      io_method: "mmap"
      frame_id: "camera"
      # See usb_cam/supported_formats for the full list.
      pixel_format: "mjpeg2rgb"
      av_device_format: "YUV422P"
      image_width: 640
      image_height: 480
      camera_name: "camera"
      camera_info_url: "package://sketch_terminator/config/camera_calibration_params.yaml"

      # -1 means "leave the camera's own default alone".
      brightness: -1
      contrast: -1
      saturation: -1
      sharpness: -1
      gain: -1
      auto_white_balance: true
      white_balance: 4000
      autoexposure: true
      exposure: 100
      # Autofocus off: the camera is at a fixed height, and refocusing mid-run
      # would silently invalidate the calibration.
      autofocus: false
      focus: -1

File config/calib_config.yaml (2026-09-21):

# Checkerboard geometry for the camera-to-robot calibration.
# Measure these on your own printed board -- getting square_size wrong scales
# every position the vision pipeline reports.

cam2world:
  ros__parameters:
    # Inner corners, not squares.
    checkerboard_width: 9
    checkerboard_height: 7
    # Side of one square, in metres.
    square_size: 0.0175
    # Offset from the robot base to the board's far corner, in metres.
    x_offset: 0.0423
    y_offset: 0.1016
    # The board is axis-aligned with the robot but mirrored, so its rotation is
    # just three signs on the diagonal.
    rotation_diagonal: [-1.0, 1.0, -1.0]
